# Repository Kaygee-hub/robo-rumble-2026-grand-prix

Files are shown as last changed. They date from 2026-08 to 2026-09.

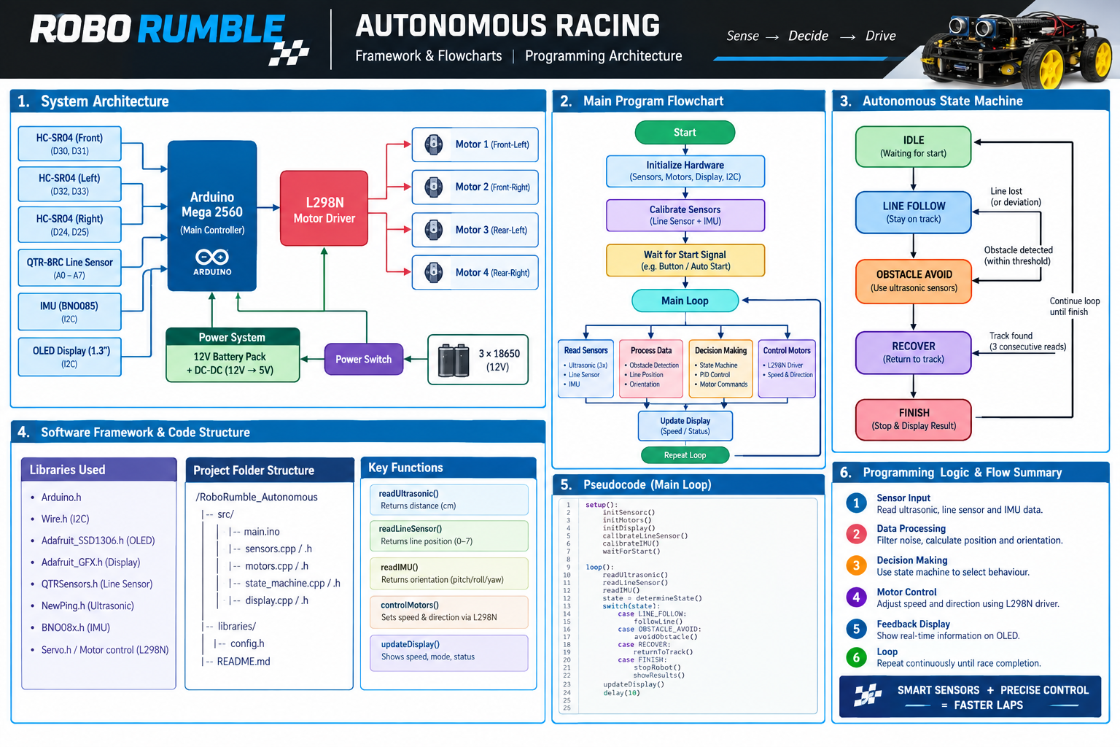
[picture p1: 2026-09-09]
robo-rumble-2026-grand-prix/Folder A - Source Code/flowcharts/robot rumble.png

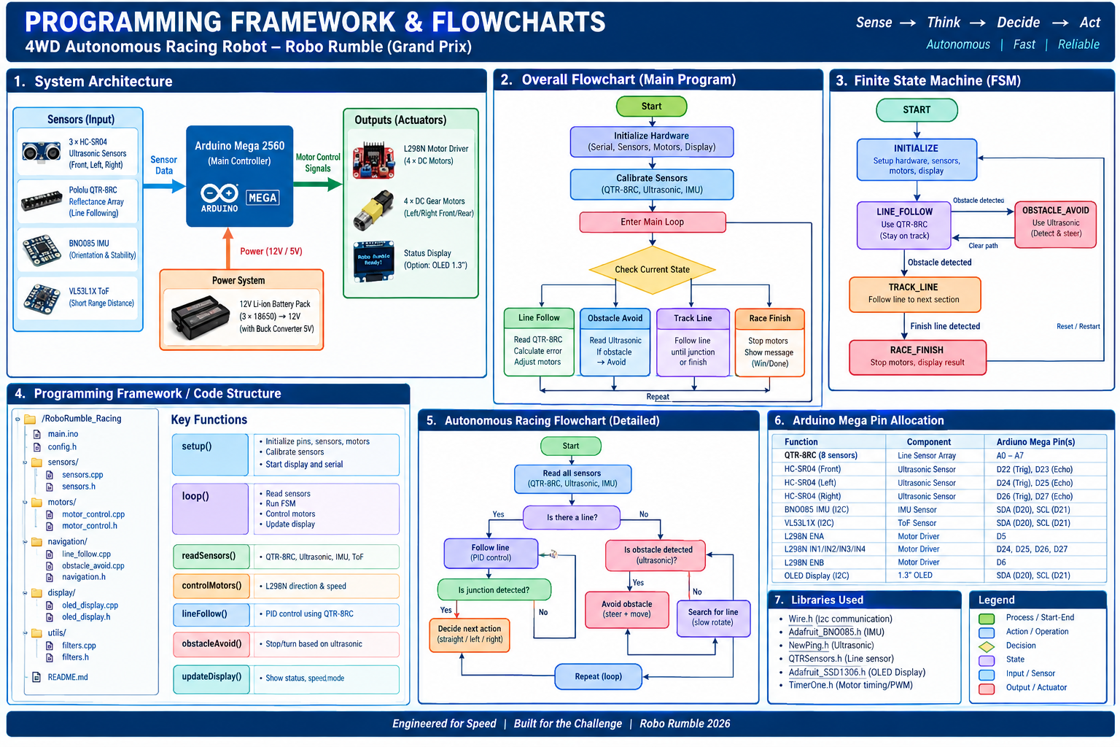
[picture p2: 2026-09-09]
robo-rumble-2026-grand-prix/Folder A - Source Code/flowcharts/flowchart and framework.png

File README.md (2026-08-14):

# 🏎️ Robo Rumble 2026: Autonomous 4WD Maze Racing Rover

> **Category:** Robo Grand Prix (Autonomous Racing)  
> **Platform:** 4WD Autonomous Mobile Robot  
> **Navigation:** Dynamic Wall-Sensing & Corridor Centering (No Line Tracking)  
> **Compliance:** Footprint $\le 50\text{ cm} \times 50\text{ cm}$ | Mass $< 5\text{ kg}$ | Integrated E-Stop Circuit  

---

## 📌 High-Level Project Summary

### What We Are Building
This project is an **autonomous 4WD mobile maze-racing rover** custom-engineered to compete in the **Robo Grand Prix** category at Robo Rumble 2026. Designed to navigate complex maze tracks without relying on surface line-following, the vehicle dynamically maps wall boundaries in real time, executes precision cornering, avoids dead ends, and maintains high velocity through narrow corridors—operating 100% autonomously with zero human intervention or remote control.

### How We Are Building It
* **Mechanical Frame:** A custom dual-deck lightweight chassis optimized for structural rigidity, staying well within the maximum $50\text{ cm} \times 50\text{ cm}$ footprint and $5\text{ kg}$ weight limit.
* **Drivetrain & Steering:** 4-wheel independent motor drive running on a differential skid-steering system managed by high-efficiency dual H-bridge motor drivers.
* **Perception & Ranging:** A multi-sensor array (Ultrasonic / Time-of-Flight distance sensors) mounted at the front, left, and right to measure corridor clearance and detect upcoming turns in real time.
* **Navigation & Control Architecture:** Embedded C++ firmware utilizing a closed-loop Proportional-Integral-Derivative (PID) wall-following algorithm combined with threshold logic for intersection decision-making.
* **Power & Safety Integrity:** Dual power management system separating microcontroller logic from high-current motor draws, featuring an accessible physical ON/OFF switch and a hardware-integrated **Emergency Stop (E-Stop)** circuit.

---

## 📂 Directory Map

```text
robo-rumble-2026-grand-prix/
│
├── 📁 Folder A - Source Code/           # Firmware, control algorithms, & logic diagrams
│   ├── 📄 src/                         # Arduino / C++ source code files
│   ├── 📄 flowcharts/                  # Navigation & maze decision logic flowcharts
│   └── 📄 README.md                    # Detailed software framework documentation
│
├── 📁 Folder B - Designs/               # Physical CAD, electrical schematics, & simulations
│   ├── 📄 Mechanical Design/           # 3D CAD renders, chassis assembly, & CAD files
│   ├── 📄 Electronic Design/           # Component selections & hardware justifications
│   ├── 📄 Schematics/                  # Annotated wiring schematics with E-Stop & Switch
│   └── 📄 Simulation/                  # Circuit & kinematic simulation test results
│
└── 📁 Folder C - Documentation/         # Submission files, budget, & attendance logs
    ├── 📄 Pitch Deck.pdf                # Official 7-slide project presentation
    ├── 📄 Bill_of_Materials.xlsx        # Itemized spreadsheet (Total Cost in RED)
    ├── 📄 Holistic_Build_Document.md    # Comprehensive technical engineering report
    ├── 📄 FQA_Attendance_Log.md         # Facilitator Q&A attendance logbook
    └── 📁 FQA_Proof/                    # Verified attendance proof screenshots

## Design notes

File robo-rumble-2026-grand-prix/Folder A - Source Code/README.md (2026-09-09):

### Software Architecture & Control Logic

1. **Sensor Processing Loop:** The firmware continuously samples three ultrasonic rangefinders (Front, Left, Right) using tight timing timeouts ($10\text{ ms}$) to ensure high execution loops without blocking execution.
2. **Obstacle Override Strategy:** If the front sensor registers an obstacle under $25\text{ cm}$, the PD controller suspends and the vehicle enters an in-place pivot turn toward whichever side offers greater clearance.
3. **Closed-Loop PD Corridor Centering:**
   * **Proportional ($K_p$):** Corrects lateral displacement relative to corridor walls.
   * **Derivative ($K_d$):** Dampens rapid oscillations and prevents high-speed weaving.
   * **Differential PWM:** Modulates left and right wheel speeds independently to maintain high velocity through sweeping corners without losing traction.

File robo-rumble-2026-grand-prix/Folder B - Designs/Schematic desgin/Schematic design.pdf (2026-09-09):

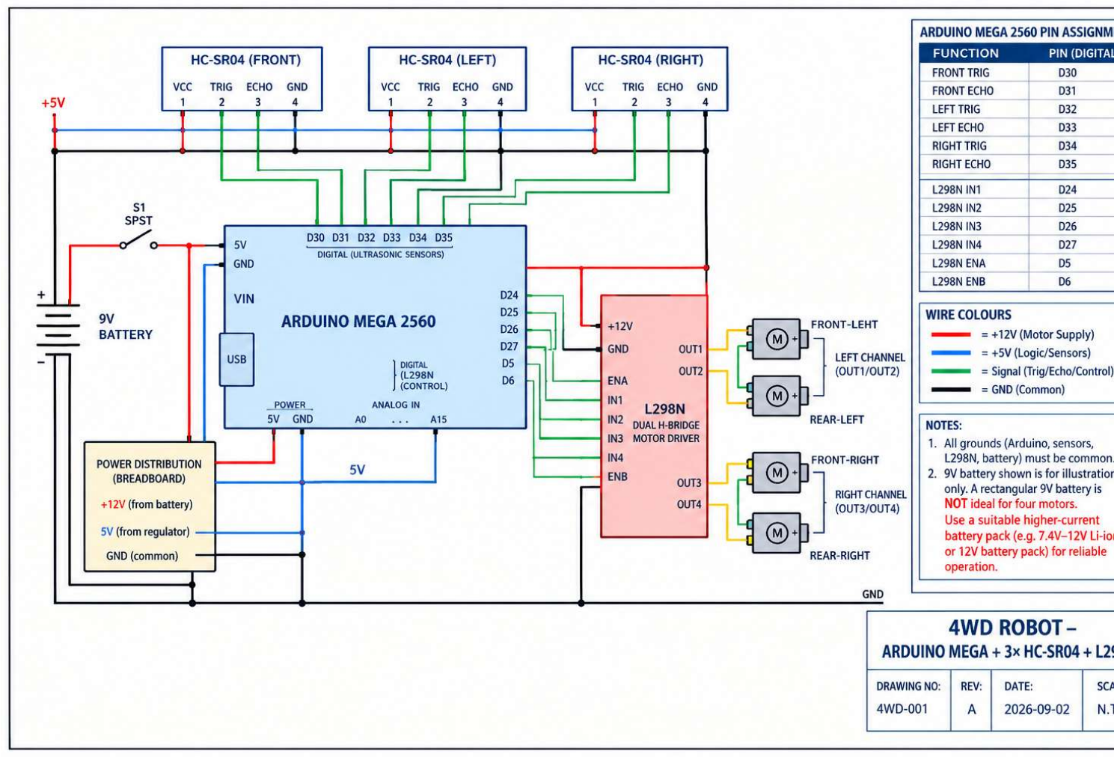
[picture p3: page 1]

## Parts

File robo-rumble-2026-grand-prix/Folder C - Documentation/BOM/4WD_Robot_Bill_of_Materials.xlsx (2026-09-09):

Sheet: BOM
4WD ROBOT — BILL OF MATERIALS
Arduino Mega 2560 + 3× HC-SR04 + L298N | Procurement BOM
Prepared: 2026-09-08 |  |  | Currency: ZAR (South African Rand) |  |  | Pricing basis: listed supplier price; VAT shown at 15% where applicable
PROJECT COST SUMMARY
Core BOM total (ex VAT) | 3854.29
VAT @ 15% | 578.14
FINAL TOTAL (INC VAT) | 4432.43
Item | Category | Component / Specification | Qty | Unit | Unit Cost (Ex VAT) | VAT / Unit | Line Total (Ex VAT) | VAT Total | Line Total (Inc VAT) | Supplier | Stock Code | Direct URL | Status / Notes
1 | Controller | Keyestudio SUPER Arduino Mega 2560 R3 Advanced + USB cable | 1 | each | 1186.77 | 178.02 | 1186.77 | 178.02 | 1364.79 | Mantech | 17M0214 | https://www.mantech.co.za/ProductInfo.aspx?Item=17M0214 | Matches Mega 2560 platform in schematic; listed ex VAT.
2 | Sensor | HC-SR04 ultrasonic reflective sensor | 3 | each | 71.19 | 10.68 | 213.57 | 32.04 | 245.61 | Mantech | 15M3173 | https://www.mantech.co.za/ProductInfo.aspx?Item=15M3173 | Three required: front, left, right.
3 | Motor Driver | Keyestudio L298N dual H-bridge motor driver module | 1 | each | 196.48 | 29.47 | 196.48 | 29.47 | 225.95 | Mantech | 17M0346 | https://www.mantech.co.za/ProductInfo.aspx?Item=17M0346 | One module drives two motor channels; motors are paired per channel.
4 | Drive Motor | 12V DC geared motor, 65RPM, 0.3A nominal, 6mm shaft | 4 | each | 496.85 | 74.53 | 1987.40 | 298.11 | 2285.51 | Mantech | 82M0808 | https://www.mantech.co.za/Stock.aspx?Query=motor%20dc%20geared | Mantech listing; verify live stock before purchase.
5 | Power | Energizer PP3 9V alkaline battery, 500–600mAh | 1 | each | 55.73 | 8.36 | 55.73 | 8.36 | 64.09 | Mantech | 310M0318 | https://www.mantech.co.za/ProductInfo.aspx?Item=310M0318 | Shown in the supplied schematic. Not recommended for sustained 4-motor operation; use a higher-current pack in the finished robot.
6 | Power Connection | 9V battery snap connector, 150mm leads | 1 | each | 3.44 | 0.52 | 3.44 | 0.52 | 3.96 | Mantech | 14M4029 | https://www.mantech.co.za/ProductInfo.aspx?Item=14M4029 | Battery clip for PP3 battery.
7 | Power | 12V→5V DC/DC buck converter, 3A, in-line USB | 1 | each | 91.30 | 13.69 | 91.30 | 13.69 | 104.99 | Communica | BDD DC/DC BUCK MOD 12TO5V USB IL | https://www.communica.co.za/products/bdd-dc-dc-buck-mod-12to5v-usb-il | Use for regulated 5V logic/sensors if supplied from a suitable motor battery.
8 | Switch | Illuminated red rocker switch, SPST, 12V, 15A | 1 | each | 10.89 | 1.63 | 10.89 | 1.63 | 12.52 | Mantech | 15M5438-X | https://www.mantech.co.za/ProductInfo.aspx?Item=15M5438-X | Main power switch; sized for low-voltage DC service.
9 | Prototyping | 830 tie-point solderless breadboard (MB-102 type) | 1 | each | 20.00 | 3.00 | 20.00 | 3.00 | 23.00 | Communica | CMU BREADBOARD 16,5X5,5CM 830TP | https://www.communica.co.za/collections/prototyping-products/products/cmu-breadboard-16-5x5-5cm-830tp | Power distribution/prototyping board.
10 | Wiring | 40-way male/female jumper ribbon, 15cm | 2 | pack | 20.00 | 3.00 | 40.00 | 6.00 | 46.00 | Communica | BMT RIBBON JUMPER 40W M/F 15CM | https://www.communica.co.za/products/bmt-ribbon-jumper-40w-m-f-15cm | Two packs provide ample logic wiring.
11 | Wiring | 40-way female/female jumper ribbon, 15cm | 1 | pack | 20.00 | 3.00 | 20.00 | 3.00 | 23.00 | Communica | HKD RIBBON JUMPER 40W F/F 15CM | https://www.communica.co.za/products/hkd-ribbon-jumper-40w-f-f-15cm | For module-to-module and breadboard connections.
12 | Mechanical / Electrical | Ultrasonic sensor mounting bracket, HC-SR04 compatible | 3 | each | 9.57 | 1.44 | 28.71 | 4.31 | 33.02 | Communica | HKD ULTRASONIC HC-SR04 BRACKET | https://www.communica.co.za/products/hkd-ultrasonic-hc-sr04-bracket | Optional but useful for clean mounting of the three sensors.
13 | Documentation / Note | Recommended high-current motor battery upgrade allowance | 0 | each | 0.00 | 0.00 | 0.00 | 0.00 | 0.00 | — | — | — | Excluded from total: the 9V PP3 shown in the reference circuit is not a suitable sustained source for four 12V motors.

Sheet: Source Notes
BOM SOURCE NOTES & ENGINEERING CHECKS
Topic | Finding | Implication | Action | Source | Date checked
9V battery vs motors | The schematic shows a 9V PP3 battery, while the listed motors are 12V geared motors. | A PP3 is unsuitable for sustained four-motor drive current. | Use a higher-current 7.4V–12V rechargeable battery pack for the actual robot; keep the 9V row only as the reference-circuit item. | https://www.mantech.co.za/ProductInfo.aspx?Item=310M0318 | 2026-09-08
HC-SR04 quantity | Three HC-SR04 modules are visible in the reference circuit. | One each for front, left and right coverage. | Procure exactly 3. | https://www.mantech.co.za/ProductInfo.aspx?Item=15M3173 | 2026-09-08
L298N | One L298N dual H-bridge is shown. | Two motor channels are available; the four motors are paired. | Procure 1 module. | https://www.mantech.co.za/ProductInfo.aspx?Item=17M0346 | 2026-09-08
Mega 2560 | The reference design uses Arduino Mega 2560. | The selected Keyestudio board is compatible with Mega 2560 R3. | Procure 1 board. | https://www.mantech.co.za/ProductInfo.aspx?Item=17M0214 | 2026-09-08
Pricing | Mantech prices displayed are ex VAT; Communica pages show ex and inc VAT. | Workbook standardizes to ex VAT + formula VAT at 15%. | Verify final cart pricing before purchase. | Supplier product pages linked in BOM. | 2026-09-08

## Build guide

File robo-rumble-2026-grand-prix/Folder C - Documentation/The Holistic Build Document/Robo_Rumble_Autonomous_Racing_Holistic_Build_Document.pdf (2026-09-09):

ROBO RUMBLE | AUTONOMOUS RACING | HOLISTIC BUILD DOCUMENT
Revision A | 08 September 2026 | Page 1

# ROBO RUMBLE

# AUTONOMOUS RACING

# Holistic Build Document

PROJECT BASELINE
Autonomous 4WD racing platform using Arduino Mega 2560, three HC-SR04 ultrasonic sensors, an L298N dual H-bridge, and four geared DC motors. The supplied 9V PP3 battery is retained only as the reference-circuit item; the finished racer should use a higher-current rechargeable motor battery.

Prepared for Robo Rumble / Robo Grand Prix — Autonomous Racing Competition date in project brief: 12 September 2026

# 1. Executive Summary

This build document defines the technical baseline for an autonomous racing robot intended for the Robo Rumble / Robo Grand Prix autonomous racing category. The objective is not simply to make a 4WD vehicle move, but to produce a compact, repeatable and serviceable platform that can sense its surroundings, make movement decisions without human steering, and convert those decisions into coordinated left/right motor commands.
The design uses an Arduino Mega 2560 as the central controller, three HC-SR04 ultrasonic sensors for front/left/right environment awareness, an L298N dual H-bridge for four-motor drive, and four geared DC motors arranged as two left motors and two right motors. The mechanical and electrical architecture is intentionally modular so that the control logic can be tuned without redesigning the full chassis.
- Primary race objective: maximize controllable speed while avoiding collisions and preserving a stable trajectory.
- Autonomy objective: all drive decisions are generated from on-board sensing and programmed logic; no steering input is required during the run.
- Engineering objective: remain inside the supplied category limits while keeping the center of mass low, wiring protected, and service access simple.
- Build objective: provide a clear verification trail from requirements -> wiring -> software -> testing -> competition readiness.
DESIGN STATUS
The document is written as Revision A using the circuit shown in the supplied reference image and the procurement BOM previously prepared. Physical prototype dimensions, exact chassis mass, motor current under load, and measured race speed must be verified on the assembled robot before a final competition release.

# 2. Background and Design Need

### 2.1 Problem Statement

In an autonomous race, the robot must react quickly enough to changes in path geometry or obstacles while maintaining traction and directional control. A manually driven 4WD platform can compensate for errors using a human operator, but an autonomous racer has to detect conditions, interpret them, and select a response inside a limited control cycle.
The technical challenge is therefore a closed-loop systems problem: sensing must be reliable, the controller must convert distance information into deterministic decisions, and the motor driver must apply those commands with enough electrical margin to avoid stalls, brownouts or uncontrolled resets.

### 2.2 Design Philosophy

- Keep the sensing geometry simple: one forward sensor establishes the primary collision-avoidance decision and two side sensors provide directional context.
- Treat left and right motor pairs as two drive channels. Differential speed between the channels provides steering without a conventional steering servo.
- Separate logic power from motor power through regulated supply and common ground architecture.
- Prefer deterministic state logic over unpredictable behavior. The robot should have explicit states such as READY, SEARCH, DRIVE, EVADE-LEFT, EVADE-RIGHT and SAFE-STOP.

- Design for debugging: named signals, documented pin assignments, accessible power switch and protected wiring.

# 3. Competition Category Constraints and Compliance

The following constraints are treated as the governing category requirements supplied for the Robo
Rumble / Robo Grand Prix autonomous racing entry. The compliance status should be rechecked against the organizer’s final technical inspection checklist immediately before scrutineering.
Constraint | Requirement | Design Response | Status | Verification
Footprint | Maximum 50 cm × 50 cm | Mechanical packaging must remain within the maximum footprint. | PASS BY DESIGN INTENT | Measure the complete outer envelope including sensors and wiring before inspection.
Mass | Maximum 5 kg | All chassis, electronics, battery and fasteners contribute to the competition mass. | TO VERIFY | Weigh the complete competition configuration.
Autonomy | Fully automatic | No manual steering/drive input during the race. | PASS BY ARCHITECTURE | Remove or disable any manual drive controls from the competition build.
Power | Battery only | Robot operates from onboard battery energy. | PASS BY ARCHITECTURE | Final battery must be onboard and isolated by the main switch.
Controller platform | Arduino / Raspberry Pi / STM accepted | The controller must belong to the accepted platform family. | PASS | Arduino Mega 2560 is used.
Category | Autonomous Racing / Grand Prix | Design emphasis is on autonomous navigation, speed, stability and repeatability. | PASS | Control strategy is closed-loop and sensor-driven.

INSPECTION GATE
A “PASS BY DESIGN INTENT” entry is not a measured certification. Final acceptance requires physical inspection of dimensions, mass, power system, wiring security and autonomous operation.

# 4. System Requirements

ID | Requirement | Meaning | Acceptance intent
FR-01 | Sense environment | Measure front, left and right distances using HC-SR04 sensors. | Three sensor channels shall be sampled repeatedly during autonomous operation.
FR-02 | Drive forward/reverse | Command coordinated motion of four motors through the L298N. | Left pair and right pair shall respond as two independently controlled drive channels.
FR-03 | Steer autonomously | Change heading using differential left/right wheel speed. | Controller shall be able to bias one side faster/slower and stop one side when required.
FR-04 | Avoid collision | Respond to insufficient | When distance falls below

| | clearance. | the configured safety threshold, drive command shall transition to an avoidance state.
FR-05 | Fail safe | Prevent uncontrolled movement on abnormal conditions. | Startup, sensor failure and battery/power faults shall lead to SAFE-STOP or controlled recovery.
FR-06 | Race repeatability | Run the same control sequence predictably. | Use deterministic thresholds, bounded delays and a documented state machine.
NFR-01 | Serviceability | Make faults easy to isolate. | Use labeled wiring, common ground rail, accessible connectors and modular electronics.
NFR-02 | Packaging | Fit the competition envelope. | Target a compact rectangular chassis below 50 × 50 cm with sensor mounts inside the outline.
NFR-03 | Electrical robustness | Avoid controller resets caused by motor transients. | Use separate regulated logic supply and sensible grounding/power distribution.

# 5. Exact Solution Architecture

### 5.1 Hardware Topology

The robot is a differential-drive 4WD platform. The Arduino Mega 2560 is the control core. Three HC-SR04 modules form a simple spatial sensing ring: FRONT, LEFT and RIGHT. The L298N provides two H-bridge channels; one channel is assigned to the left motor pair and the other to the right motor pair. Steering is achieved by creating a speed or direction difference between those two sides.

Subsystem | Component | Role
Controller | Arduino Mega 2560 | Runs sensor acquisition, decision logic and motor commands.
Front sensing | HC-SR04 #1 | Primary collision/clearance sensor.
Left sensing | HC-SR04 #2 | Left-side clearance / wall context.
Right sensing | HC-SR04 #3 | Right-side clearance / wall context.
Motor interface | L298N dual H-bridge | Converts controller IN/EN commands into power to the motor pairs.
Drive train | 4 × 12V geared DC motors | Two motors mechanically placed on the left side, two on the right.
Power | Onboard battery + regulated 5V rail | Motor rail feeds L298N; regulated 5V rail feeds controller/sensors as appropriate.
Main isolation | SPST power switch | Allows safe energization/de-energization of the robot.

### 5.2 Electrical Pin Assignment

Signal | Mega pin | Function
FRONT TRIG | D30 | HC-SR04 front
FRONT ECHO | D31 | HC-SR04 front
LEFT TRIG | D32 | HC-SR04 left
LEFT ECHO | D33 | HC-SR04 left
RIGHT TRIG | D34 | HC-SR04 right

RIGHT ECHO | D35 | HC-SR04 right
L298N IN1 | D24 | Drive control
L298N IN2 | D25 | Drive control
L298N IN3 | D26 | Drive control
L298N IN4 | D27 | Drive control
L298N ENA | D5 | Left-channel enable / PWM
L298N ENB | D6 | Right-channel enable / PWM

### 5.3 Wiring Rules

- All grounds are common: Arduino, HC-SR04 modules, L298N logic/control ground and battery negative must share a defined ground path.
- Motor current must not be routed through the breadboard logic traces where a dedicated motor-power path is available.
- Use a regulated 5V supply for the Mega/sensors where the battery voltage is higher than 5V.
- Keep sensor signal wires away from high-current motor wires where practical, and secure loose leads so vibration cannot change the sensor orientation.
- Use the main switch to isolate the robot before connecting or disconnecting wiring.

### 5.4 Reference Electrical Schematic

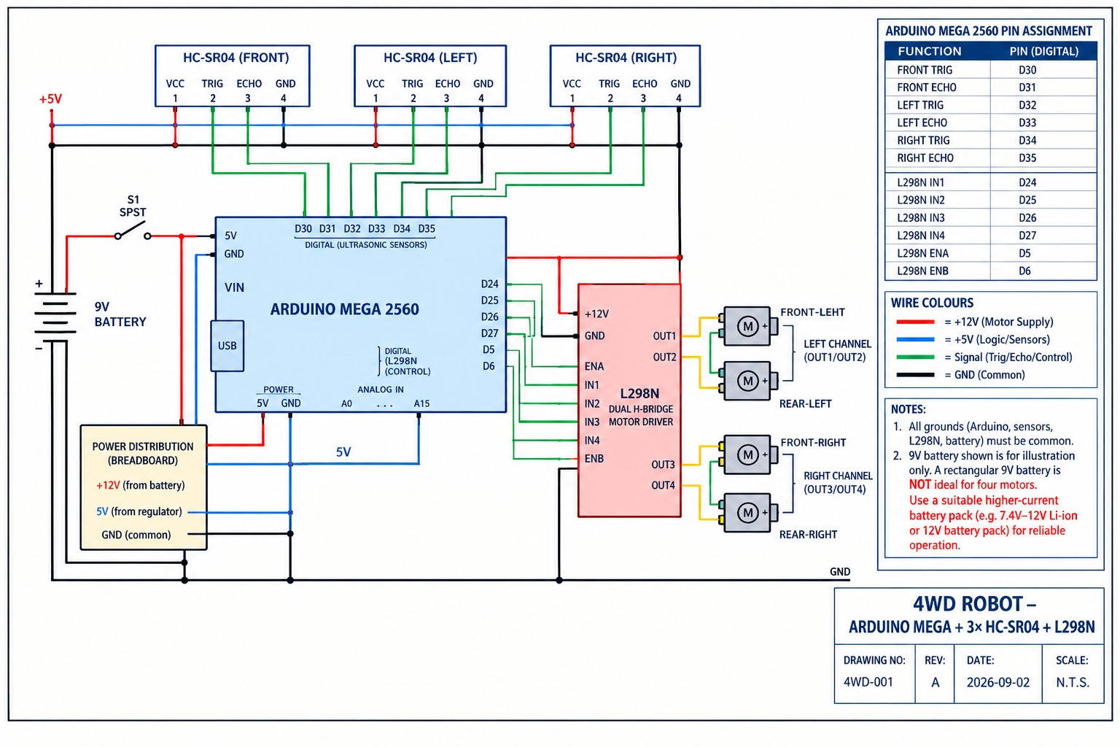
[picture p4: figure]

Figure 1 — Reference schematic. Treat the 9V PP3 as illustrative only; the finished four-motor platform needs a higher-current rechargeable pack.

# 6. Mechanical Design

### 6.1 Chassis Architecture

The mechanical design should use a rigid rectangular base with four driven wheels located symmetrically around the centerline. Heavy components such as the battery and motor driver should sit low and near the geometric center. The Arduino and sensor wiring can sit on an upper electronics deck provided the resulting center of gravity remains low enough to limit wheel lift during hard turns.
- Four-wheel drive provides traction and redundancy; left and right motor pairs act as logical drive channels.
- Sensor brackets should keep the three HC-SR04 faces square to their intended directions. Small angular errors can create uneven distance readings and false steering decisions.
- Protect electronics from wheel spray, loose wires and impact contact. A simple raised electronics plate is preferred to mounting modules directly against the floor.
- Fasteners should be mechanically locked against vibration where required. Cable ties or printed cable guides should restrain heavy motor leads.

### 6.2 Packaging and Envelope Control

Parameter | Design guidance
Maximum allowed footprint | 500 × 500 mm
Target design margin | Keep the measured outer envelope comfortably below the limit instead of designing to the boundary.
Sensor extension | Sensor brackets and connector plugs count toward the practical envelope and should be included in inspection measurement.
Battery placement | Low and central to reduce pitch/roll moment during acceleration and avoidance.
Maintenance | Allow access to the main switch, battery connector, controller USB port and motor-driver terminals.

### 6.3 Drive Geometry and Steering

For differential steering, the robot yaw response depends on the speed difference between the left and right sides. A simple normalized control law is:
CONTROL LAW
left_cmd = base_speed + steer_bias; right_cmd = base_speed - steer_bias. Positive steer_bias produces a left/right speed difference; sign convention must be fixed during software commissioning.

The exact steering gain and base speed should be tuned experimentally because motor torque, wheel diameter, surface friction, battery voltage and chassis loading determine the actual turning response.

# 7. Sensing and Perception

### 7.1 HC-SR04 Operating Concept

Each HC-SR04 is activated by a trigger pulse and reports the time between the transmitted ultrasonic burst and the returning echo. Distance is calculated from the measured round-trip time and the speed of sound. A commonly used relationship is d = v_sound × t / 2. At approximately 20 °C, v_sound is about 343 m/s.

For an autonomous racer, raw readings should not be used blindly. The controller should reject obviously invalid readings, apply a small median or moving-average filter where needed, and use thresholds with hysteresis so the robot does not chatter between two movement states.

### 7.2 Sensor Placement

Sensor | Purpose | Mounting | Control use
Front | Primary collision clearance | Forward-facing on centerline | Controls emergency braking / avoidance decision
Left | Left clearance / corridor context | Forward-left or left-facing | Biases steering away from close left boundary
Right | Right clearance / corridor context | Forward-right or right-facing | Biases steering away from close right boundary

### 7.3 Recommended Measurement Logic

1. Trigger one sensor and measure echo time.
2. Convert the valid time measurement to distance.
3. Reject readings outside the sensor’s usable range or with a timeout.
4. Repeat for the other sensors using a schedule that prevents overlapping acoustic bursts.
5. Feed the filtered values into the decision state machine.
6. If the front distance falls below the emergency threshold, reduce base speed immediately and select the avoidance direction using side clearances.
IMPORTANT
The three ultrasonic sensors should not be fired simultaneously. Staggering measurements reduces the chance that one sensor hears another sensor’s echo.

# 8. Motor Drive and Power System

### 8.1 Motor Driver Topology

The L298N is a dual H-bridge. In this four-motor implementation, the two left motors are paired on one bridge channel and the two right motors are paired on the second bridge channel. IN1/IN2 determine the left channel direction; IN3/IN4 determine the right channel direction; ENA and ENB enable the channels and can accept PWM for speed control.

### 8.2 Recommended Command Table

Action | Left channel | Right channel | Intent
FORWARD | IN1=1, IN2=0 | IN3=1, IN4=0 | Both sides forward
REVERSE | IN1=0, IN2=1 | IN3=0, IN4=1 | Both sides reverse
LEFT | Reduced left / stopped left | Right forward | Pivot or arc left, depending on tuning
RIGHT | Left forward | Reduced right / stopped right | Pivot or arc right, depending on tuning
BRAKE/STOP | 0/0 or implementation-specific | 0/0 or implementation-specific | Stop command; verify module behavior on the actual board

### 8.3 Battery and Power Budget

The procurement BOM contains a 9V PP3 battery because it is shown in the reference circuit. That battery is not an appropriate sustained source for four 12V geared motors. The competition build therefore requires a higher-current rechargeable battery pack that can supply the motor load and transient current without excessive voltage sag.
- Motor rail: choose a battery voltage compatible with the selected geared motors and the L298N operating range.
- Logic rail: derive a regulated 5V supply for the Arduino/sensors when the battery voltage is above 5V.
- Common ground: connect battery negative, driver ground and logic ground at a deliberate distribution point.
- Protection: include a master switch and, where practical, a fuse or current-limiting protection appropriate to the pack and wiring.
POWER WARNING
Do not treat the 9V PP3 as the final race battery for a four-motor drive train. The final hardware configuration must be verified for motor voltage, driver dissipation, current capability and battery discharge rating.

# 9. Autonomous Control Software

### 9.1 Software Architecture

Module | Responsibility
Initialization | Configure I/O, PWM channels, sensor timeouts and safety defaults.
Sensor service | Acquire front/left/right measurements on a staggered schedule.
Filtering | Validate and smooth readings; mark invalid data explicitly.
Decision engine | Convert distance context into a state such as DRIVE or EVADE.
Motion controller | Map the state into left/right motor direction and PWM commands.
Safety monitor | Stop or slow the robot when sensing fails, battery/logic resets occur or an invalid state is detected.
Telemetry/debug | During development only, expose readings and states through Serial; remove or minimize blocking debug output for final racing timing.

### 9.2 Suggested State Machine

State | Action | Entry condition
READY | Waiting for start condition; motors disabled. | Main switch on; controller healthy.
DRIVE | Normal forward racing. | No immediate obstacle and sensors valid.
SLOW | Reduce speed before close geometry. | Front distance entering warning band.
EVADE-LEFT | Bias or pivot left. | Left side offers more clearance than right, or route logic selects left.
EVADE-RIGHT | Bias or pivot right. | Right side offers more clearance than left, or route logic selects right.
RECOVER | Controlled re-acquisition of heading. | Robot has completed avoidance and needs to return to preferred trajectory.
SAFE-STOP | Motors disabled. | Sensor timeout, controller fault, emergency stop condition or shutdown.

### 9.3 Pseudocode

START
initialize pins, PWM, sensors, safety defaults motorStop()
state <- READY

LOOP
front <- readFront()
left <- readLeft()
right <- readRight()

if invalid(front, left, right):
state <- SAFE-STOP
else if front < EMERGENCY_DISTANCE:
if left > right: state <- EVADE-LEFT else: state <- EVADE-RIGHT
else if front < WARNING_DISTANCE: state <- SLOW
else:
state <- DRIVE

applyMotorCommand(state, left, right, front) waitUntilNextControlCycle()

# 10. Race Control and Tuning Strategy

### 10.1 Speed Strategy

A fast robot is not the same as a successful racer. The control strategy should trade speed for predictability near obstacles or tight sections of the course. A practical implementation uses at least two speed bands: a higher base speed in clear space and a reduced speed when the front sensor enters the warning zone.

### 10.2 Thresholds

Parameter | Purpose | Engineering basis
WARNING_DISTANCE | Start reducing speed | Tune from measured stopping distance + margin.
EMERGENCY_DISTANCE | Initiate decisive avoidance or stop | Must exceed the robot’s worst-case stopping distance at the selected race speed.
SIDE_BIAS_THRESHOLD | Select left vs right path | Derived from difference between left and right measured clearance.
SENSOR_TIMEOUT | Declare sensing fault | Short enough to fail safe, long enough not to false-trigger on noisy returns.

### 10.3 Basic Stopping-Distance Method

For commissioning, measure actual stopping distance instead of assuming a theoretical value. Conduct repeat runs at the intended race speed, record the distance from obstacle detection to complete stop, and define the emergency threshold as the measured worst case plus a safety margin. This converts the avoidance logic from an arbitrary number into a verified engineering parameter.

# 11. Verification and Testing Plan

ID | Test | Method | Pass criterion
V-01 | Power-up test | Switch on; Arduino starts; no | No unintended motion; logic

| | motor movement at startup. | supply stable.
V-02 | Sensor range test | Place target at known distances front/left/right. | Reported distance tracks target with acceptable repeatability.
V-03 | Sensor cross-talk test | Trigger sensors in sequence with all three mounted. | No persistent false echoes caused by another sensor.
V-04 | Motor direction test | Command each drive channel separately. | Left pair and right pair rotate in the documented directions.
V-05 | Differential steering test | Run forward with fixed left/right PWM offsets. | Robot turns in the expected direction consistently.
V-06 | Obstacle avoidance test | Drive toward obstacle at controlled speed. | Robot slows/turns before collision; repeated runs are consistent.
V-07 | Full autonomous lap test | Run complete course with no manual intervention. | Completes the course within the intended safety and repeatability envelope.
V-08 | Power endurance test | Operate at representative race load. | No controller resets, dangerous heating or loose connections.
V-09 | Inspection test | Measure envelope and mass. | Footprint <= 50x50 cm and mass <= 5 kg.

# 12. Risk, Failure Modes and Mitigations

Failure mode | Effect | Risk | Mitigation
Motor current overload | L298N heating / voltage drop | High | Use suitable battery/driver thermal margin; test loaded drive; avoid stalled motors.
9V PP3 used in final build | Rapid voltage sag / motors unable to deliver torque | High | Replace reference battery with a suitable high-current rechargeable pack.
Sensor cross-talk | False distance reading | Medium | Stagger sensor triggering; filter invalid readings.
Loose motor wire | Intermittent drive / resets | Medium | Strain relief, locking connectors and post-vibration inspection.
Common-ground error | Erratic sensors / driver behavior | High | Use a defined common ground distribution point and continuity test.
Sensor misalignment | Robot steers unpredictably | Medium | Rigid brackets and alignment check during pre-run inspection.
Controller reset | Loss of autonomy | High | Separate logic power from motor rail; minimize electrical noise and brownout risk.
Excess speed for course | Overshoot / collision | Medium | Use speed bands and verify stopping distance empirically.

# 13. Bill of Materials and Cost Position

The separate procurement workbook prepared for this project totals the currently listed reference build at R4,432.43 including VAT. That total includes the 9V PP3 line shown in the reference circuit; the recommended higher-current final motor battery is excluded from the current total and must be budgeted separately.

Group | Qty | Component | Cost / note
Controller | 1 | Arduino Mega 2560 | R1,364.79 incl. VAT (from

| | | current BOM)
Ultrasonic sensing | 3 | HC-SR04 | R81.87 incl. VAT each (from current BOM)
Motor driver | 1 | L298N | R226.95 incl. VAT (from current BOM)
Drive motors | 4 | 12V geared 65RPM motors | R571.38 incl. VAT each (from current BOM)
Reference power | 1 | 9V PP3 | Not suitable as the final motor battery
Other electrical/mechanical | Various | Switch, buck, breadboard, jumpers, brackets, clip | Included in BOM total

CURRENT BOM TOTAL
R4,432.43 incl. VAT — visually treated as a reference procurement total only. Final race cost should be updated after selecting the compliant high-current battery and any final chassis/manufacturing hardware.

# 14. Build, Assembly and Service Procedure

7. Assemble the chassis and verify wheel alignment without powering electronics.
8. Mount the four motors and confirm that all wheels spin freely and have the intended direction convention.
9. Install the L298N close to the motor wiring but protected from impact and conductive debris.
10. Mount the Arduino Mega and establish the regulated logic power rail.
11. Install and align the three HC-SR04 sensors with rigid brackets.
12. Create the common ground distribution and then route sensor/control signals separately from motor-current wiring.
13. Load the autonomous control firmware and execute startup, direction and sensor tests individually.
14. Only after bench verification, energize the complete system with the final competition battery.

### 14.1 Pre-Race Checklist

☐ Footprint measured below 50 × 50 cm.
☐ Complete robot mass measured below 5 kg.
☐ Battery securely mounted and isolated by main switch. ☐ No loose wires near wheels, gears or moving linkages. ☐ All three sensor brackets tight and correctly oriented. ☐ Motor direction verified.
☐ Sensor values verified before every run.
☐ Autonomy tested without manual steering.
☐ Emergency/stop procedure understood by the team.

# 15. Technical Rationale and Expected Performance

The main advantage of the selected architecture is simplicity. The Arduino Mega provides many digital I/O resources, the three ultrasonic modules are straightforward to integrate, and the L298N reduces the motor interface to two drive channels. This lowers software complexity and makes the first autonomous prototype easy to debug.

The main limitation is power and drive efficiency. The L298N introduces voltage loss and heat compared with newer MOSFET-based motor drivers, and the reference 9V PP3 cannot support sustained four-motor racing. Therefore, the performance envelope must be characterized experimentally rather than assumed. The highest-value improvements are a suitable high-current battery, robust power distribution, wheel alignment, sensor timing, and tuned differential steering.

### 15.1 Engineering Metrics to Record

ID | Metric | Unit | Measurement method
M-01 | Top sustainable speed | m/s | 10-run average on the actual race surface
M-02 | Stopping distance | cm | Worst case at race speed
M-03 | Sensor repeatability | cm | Standard deviation over repeated stationary tests
M-04 | Motor-driver temperature rise | °C | After representative continuous drive
M-05 | Runtime / course attempts | min or laps | Measure under representative battery condition
M-06 | Mass | kg | Competition configuration
M-07 | Footprint | mm × mm | Maximum external dimensions

# 16. Why This Fits Autonomous Racing

This platform is deliberately optimized around the key demands of autonomous racing: short decision cycles, simple but useful environmental perception, differential traction control, compact packaging and repeatable behavior. The robot does not depend on a human steering command during the run. Instead, the on-board controller closes the loop between measured distance and motor command.
RACING PRINCIPLE
Consistency beats theoretical peak speed. The preferred setup is the fastest configuration that can repeatedly complete the course without sensor-induced oscillation, motor-driver thermal problems or loss of traction.

# 17. Conclusion

The documented solution is a practical autonomous 4WD racer built around an Arduino Mega 2560, three ultrasonic sensors and a dual-channel motor driver. It meets the stated autonomous architecture requirements and provides a clear path from electrical integration to race tuning. The remaining engineering work is primarily validation: measure the complete robot, select and qualify the final high-current battery, tune the autonomous thresholds, and verify repeated full-course performance. Revision A should be treated as the build-control baseline. Any change to controller, sensor count, motor driver, battery voltage, wheel diameter or pin assignment should trigger a controlled revision so that the wiring diagram, firmware and procurement list remain consistent.

# Appendix A — Procurement Reference

The current BOM workbook should be treated as the procurement source of truth for component names, quantities, supplier references, stock codes and direct product URLs. Before purchase, verify live pricing, stock and the final battery specification.
Workbook: /mnt/data/4WD_Robot_Bill_of_Materials.xlsx

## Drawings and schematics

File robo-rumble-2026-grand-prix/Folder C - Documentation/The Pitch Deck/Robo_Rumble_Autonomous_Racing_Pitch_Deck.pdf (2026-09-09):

# ROBO

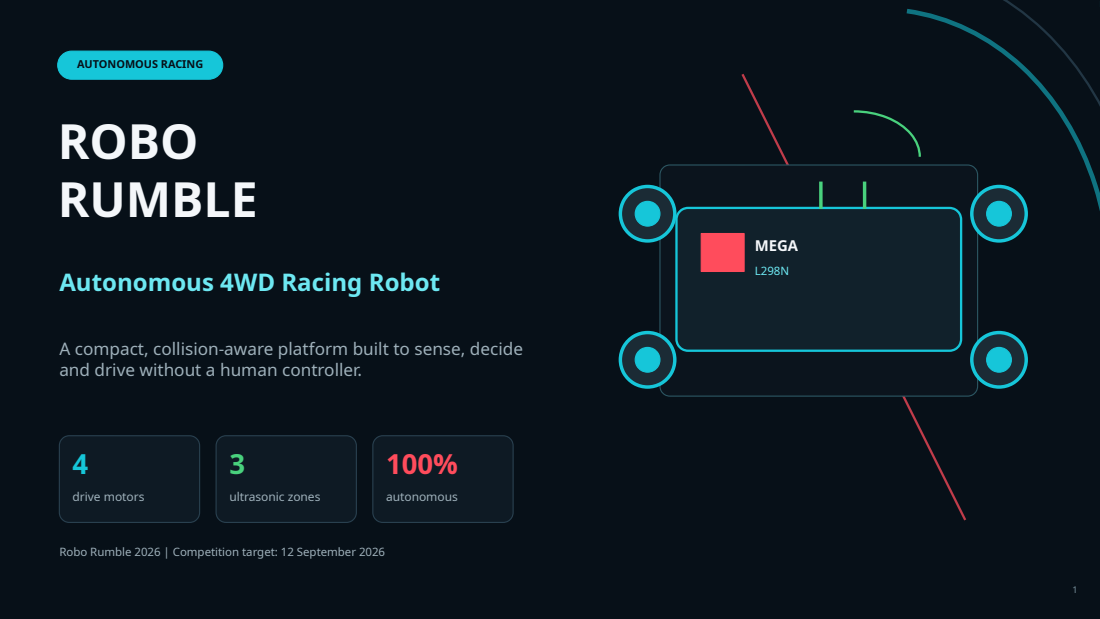
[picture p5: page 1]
ROBO RUMBLE 2026 | AUTONOMOUS RACING; KGAOGELO / KICT; AUTONOMOUS RACING; RUMBLE; drive motors; ultrasonic zones; autonomous; MEGA

Autonomous 4WD Racing Robot

A compact, collision-aware platform built to sense, decide
and drive without a human controller.

Robo Rumble 2026 | Competition target: 12 September 2026

01 | THE PROBLEM

# Autonomous racing needs more than speed

The challenge is maintaining momentum while reacting to changing track conditions in real time.

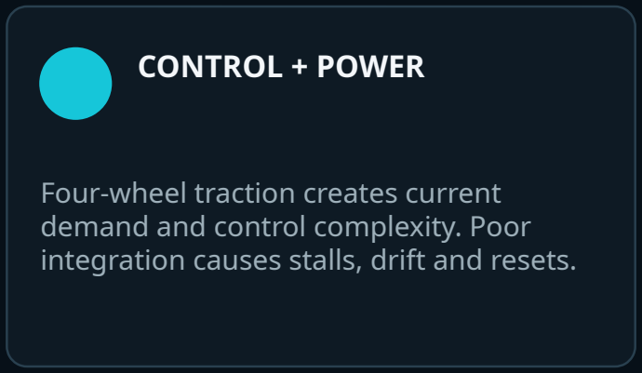
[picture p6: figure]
CONTROL + POWER; Four-wheel traction creates current demand and control complexity. Poor

integration causes stalls, drift and resets.

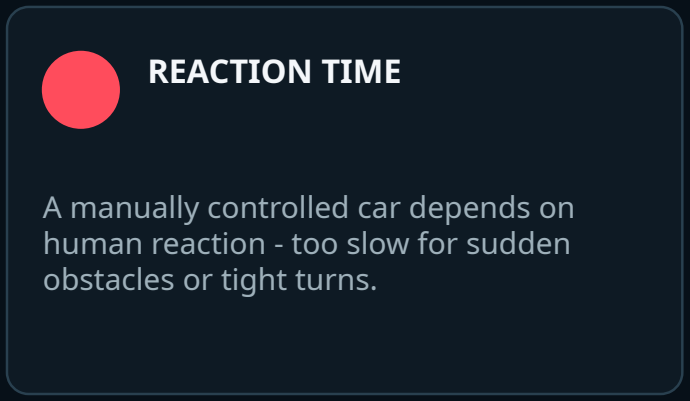
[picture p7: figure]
REACTION TIME; A manually controlled car depends on human reaction - too slow for sudden obstacles or tight turns.
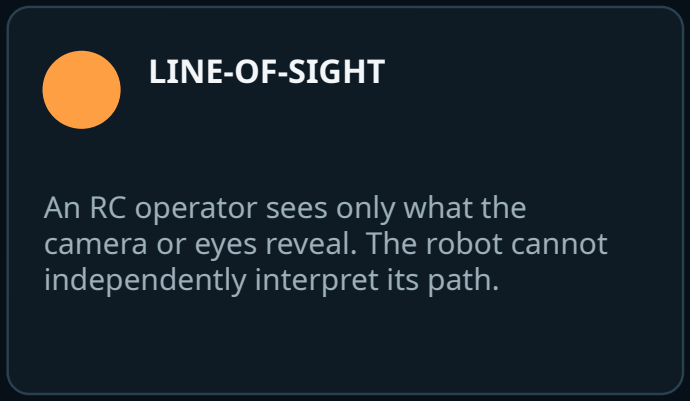
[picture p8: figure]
LINE-OF-SIGHT; An RC operator sees only what the camera or eyes reveal. The robot cannot independently interpret its path.
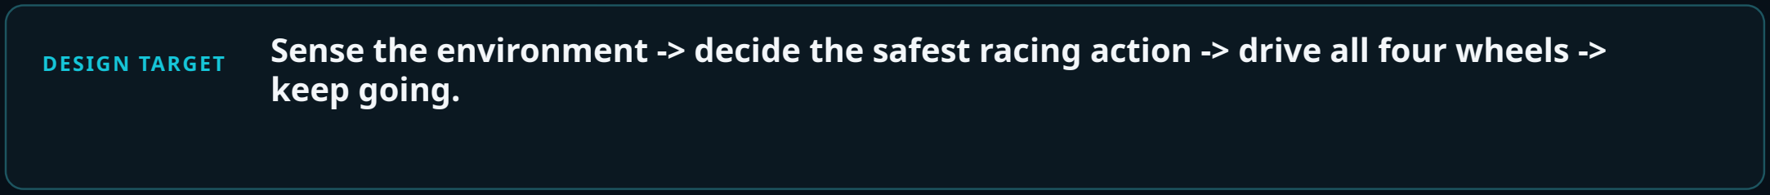
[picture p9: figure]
keep going.

DESIGN TARGET Sense the environment -> decide the safest racing action -> drive all four wheels ->

Competition brief used: compact footprint, battery-powered, fully autonomous operation.

# A three-zone sensing system wrapped around a 4WD drive platform

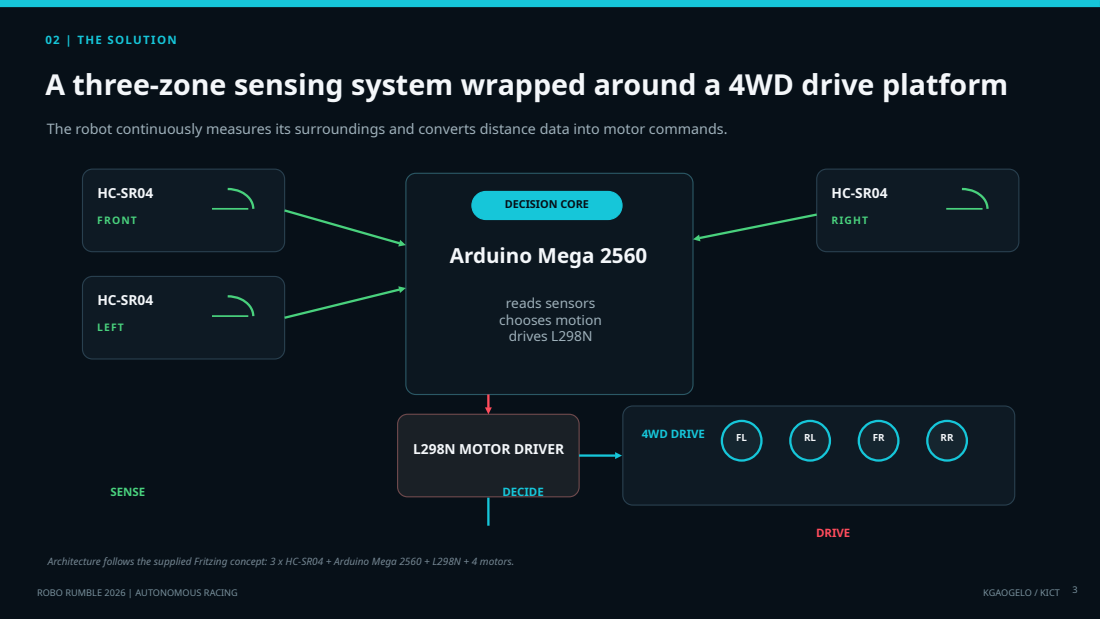
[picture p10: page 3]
02 | THE SOLUTION; DECISION CORE; Arduino Mega 2560; reads sensors chooses motion drives L298N; FRONT; LEFT; RIGHT; L298N MOTOR DRIVER; 4WD DRIVE; SENSE; DECIDE; DRIVE

The robot continuously measures its surroundings and converts distance data into motor commands.

Architecture follows the supplied Fritzing concept: 3 x HC-SR04 + Arduino Mega 2560 + L298N + 4 motors.

Simple rules. Fast decisions. Fewer collisions.

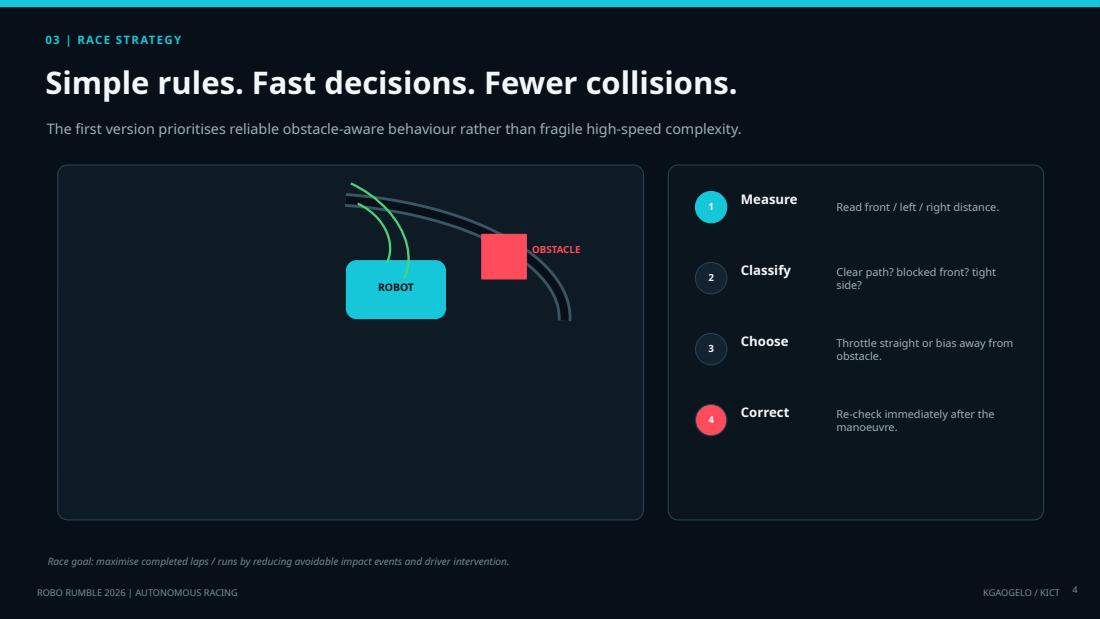
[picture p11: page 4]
03 | RACE STRATEGY; ROBOT; OBSTACLE; Measure; Read front / left / right distance.; Classify; Clear path? blocked front? tight; side?; Choose; Throttle straight or bias away from; obstacle.; Correct; Re-check immediately after the; manoeuvre.

The first version prioritises reliable obstacle-aware behaviour rather than fragile high-speed complexity.

Race goal: maximise completed laps / runs by reducing avoidable impact events and driver intervention.

04 | MARKETABILITY

# A competition robot can become a reusable robotics platform

The same sensing-and-drive architecture transfers to education, demos and lightweight indoor automation.

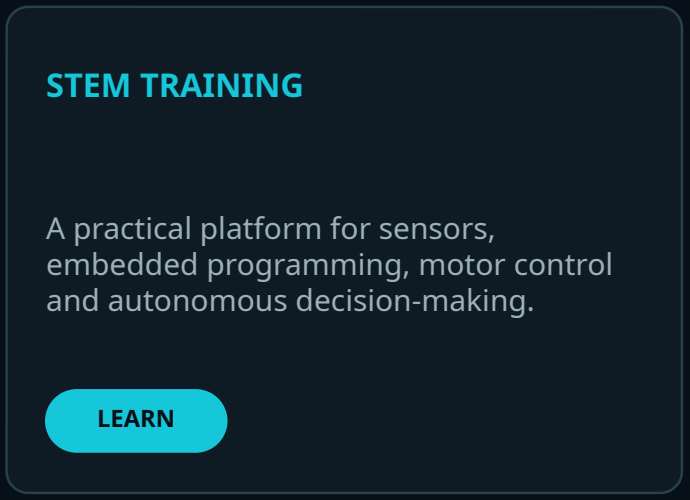
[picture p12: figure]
STEM TRAINING; A practical platform for sensors, embedded programming, motor control and autonomous decision-making.; LEARN
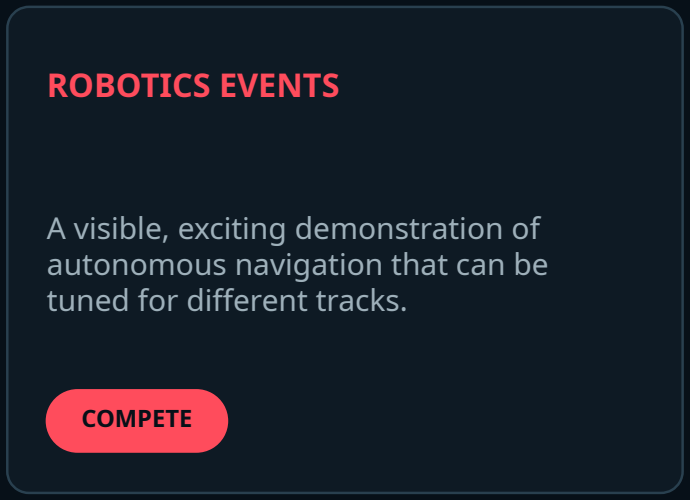
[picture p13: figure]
ROBOTICS EVENTS; A visible, exciting demonstration of autonomous navigation that can be tuned for different tracks.; COMPETE
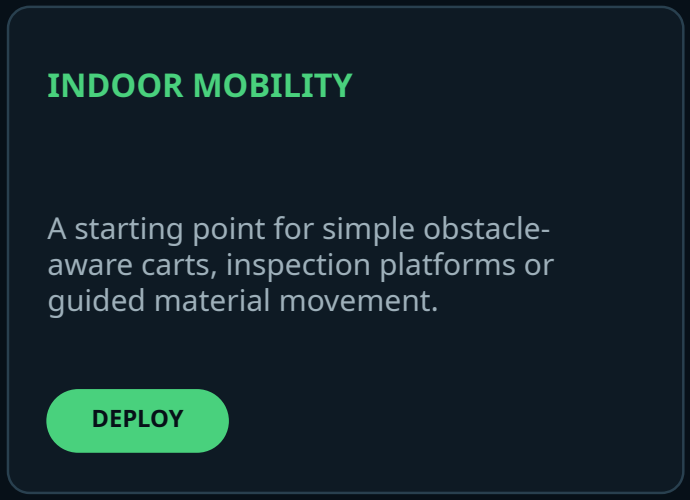
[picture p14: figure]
INDOOR MOBILITY; A starting point for simple obstacle- aware carts, inspection platforms or guided material movement.; DEPLOY
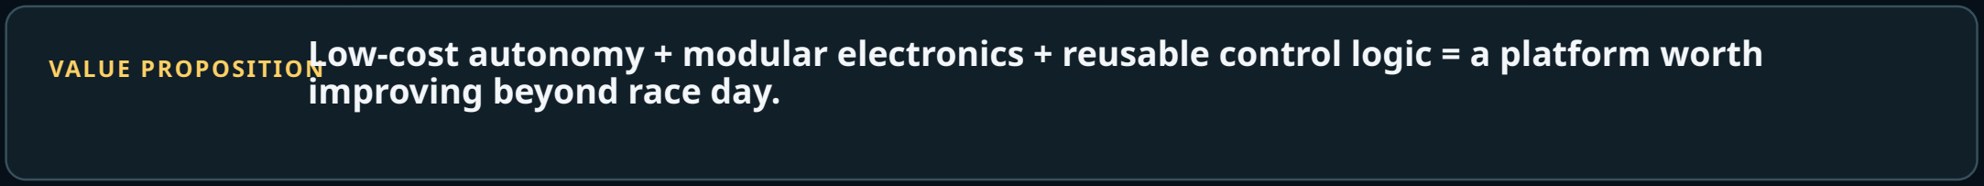
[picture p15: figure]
improving beyond race day.

VALUE PROPOSITIONLow-cost autonomy + modular electronics + reusable control logic = a platform worth

Commercial framing is a project proposition, not a claim of current commercial deployment.

05 | COST

# Built with accessible off-the-shelf electronics

The current BOM stays within a student-project budget while keeping the platform serviceable and upgradeable.

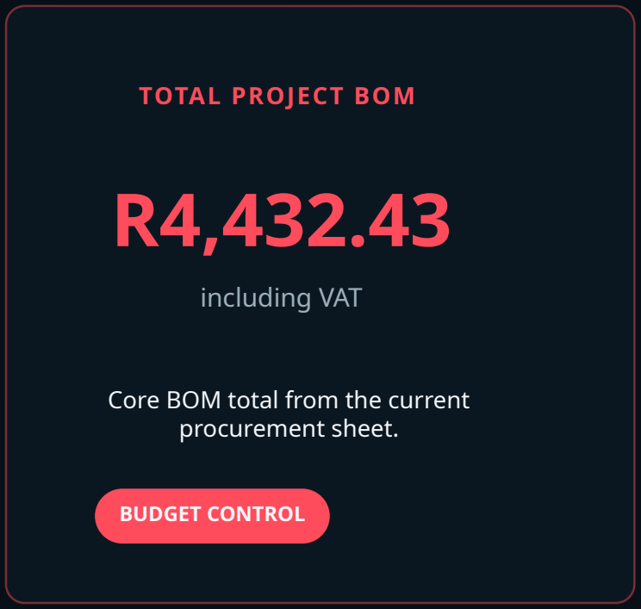
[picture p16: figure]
TOTAL PROJECT BOM R4,432.43; including VAT; Core BOM total from the current procurement sheet.; BUDGET CONTROL

COST DRIVERS

4 x drive motors | ~R2,285
Mega + sensors + L298N | ~R1,485
Power + wiring + mechanics | ~R662

POWER NOTE: the 9V PP3 shown in the reference circuit is not suitable for sustained four-motor operation; use a higher-current rechargeable pack in the finished race robot.

Pricing basis: current BOM sheet, ZAR; verify supplier stock and final cart pricing before purchase.

# The person behind the machine

06 | TEAM; Kgaogelo “KayGee”; TEAM LEAD; EMBEDDED SYSTEMS; MECH / ELECTRICAL; TEST / TUNING

Hands-on integration across mechanics, electronics, firmware and race testing.

Project direction + race strategy

Arduino control + sensor logic

Drive train + wiring integration

Track trials + decision-rule tuning

MISSION Build an autonomous robot that is fast enough to compete,

simple enough to repair, and smart enough to finish.

Team slide uses the uploaded member photo supplied in this conversation.

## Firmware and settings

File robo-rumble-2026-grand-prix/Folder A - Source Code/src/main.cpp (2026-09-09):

/**
 * Robo Rumble 2026 — Robo Grand Prix (Autonomous Maze Racing)
 * 4WD Rover High-Speed Wall-Centering & Navigation Firmware
 * 
 * Hardware:
 * - Microcontroller: Arduino Uno / Nano / Mega
 * - Driver: L298N / DRV8833 Dual H-Bridge
 * - Sensors: 3x HC-SR04 Ultrasonic Sensors (Front, Left, Right)
 */

#include <Arduino.h>

// ==========================================
// 1. PIN CONFIGURATIONS
// ==========================================

// Motor Driver Pins (L298N / DRV8833)
const int ENA = 5;   // PWM Speed Control Left Motors
const int IN1 = 4;   // Direction Left Forward
const int IN2 = 7;   // Direction Left Reverse

const int ENB = 6;   // PWM Speed Control Right Motors
const int IN3 = 8;   // Direction Right Forward
const int IN4 = 12;  // Direction Right Reverse

// Ultrasonic Sensor Pins
const int TRIG_FRONT = 2;
const int ECHO_FRONT = 3;

const int TRIG_LEFT  = 9;
const int ECHO_LEFT  = 10;

const int TRIG_RIGHT = 11;
const int ECHO_RIGHT = 13;

// ==========================================
// 2. RACING TUNING PARAMETERS
// ==========================================
const int MAX_SPEED       = 255;  // Full speed PWM (0 - 255)
const int BASE_SPEED      = 220;  // Cruising speed on straightaways
const int MIN_SPEED       = 100;  // Minimum wheel PWM during tight turns

const int FRONT_THRESHOLD = 25;   // Critical distance (cm) to trigger cornering
const int SENSOR_TIMEOUT  = 10000; // Timeout in microseconds (~170cm max distance limit)

// PD (Proportional-Derivative) Control Gains
float Kp = 6.5;                   // Steering aggression (Increase if weaving too late)
float Kd = 3.2;                   // Steering damping (Increase if rover oscillates/wobbles)

// Steering variables
float currentError = 0.0;
float lastError    = 0.0;

// Sensor Distance Variables (cm)
float distFront, distLeft, distRight;

// ==========================================
// 3. FUNCTION DECLARATIONS
// ==========================================
float getDistance(int trigPin, int echoPin);
void readAllSensors();
void setMotorSpeeds(int leftSpeed, int rightSpeed);
void executePivotTurn();

// ==========================================
// 4. SETUP
// ==========================================
void setup() {
  // Motor Pins
  pinMode(ENA, OUTPUT);
  pinMode(ENB, OUTPUT);
  pinMode(IN1, OUTPUT);
  pinMode(IN2, OUTPUT);
  pinMode(IN3, OUTPUT);
  pinMode(IN4, OUTPUT);

  // Ultrasonic Pins
  pinMode(TRIG_FRONT, OUTPUT);
  pinMode(ECHO_FRONT, INPUT);
  pinMode(TRIG_LEFT, OUTPUT);
  pinMode(ECHO_LEFT, INPUT);
  pinMode(TRIG_RIGHT, OUTPUT);
  pinMode(ECHO_RIGHT, INPUT);

  // Initial Motor State: Stopped
  setMotorSpeeds(0, 0);

  // Short delay before startup run
  delay(1000);
}

// ==========================================
// 5. MAIN CONTROL LOOP
// ==========================================
void loop() {
  readAllSensors();

  // -------------------------------------------------------------
  // CONDITION 1: OBSTACLE AHEAD -> HARD CORNERING / PIVOT
  // -------------------------------------------------------------
  if (distFront < FRONT_THRESHOLD && distFront > 0) {
    executePivotTurn();
  } 
  // -------------------------------------------------------------
  // CONDITION 2: CLEAR AHEAD -> HIGH-SPEED PD WALL-CENTERING
  // -------------------------------------------------------------
  else {
    // Determine wall centering strategy based on available side walls
    if (distLeft > 0 && distRight > 0 && distLeft < 60 && distRight < 60) {
      // Both walls detected: Center in middle of corridor
      currentError = distLeft - distRight;
    } 
    else if (distLeft > 0 && distLeft < 60) {
      // Only Left wall detected: Maintain 20 cm distance from Left wall
      currentError = (distLeft - 20.0) * 1.5;
    } 
    else if (distRight > 0 && distRight < 60) {
      // Only Right wall detected: Maintain 20 cm distance from Right wall
      currentError = (20.0 - distRight) * 1.5;
    } 
    else {
      // Open space / No close side walls: Drive straight forward
      currentError = 0.0;
    }

    // Calculate PD Steering Correction
    float derivative = currentError - lastError;
    float steeringAdjustment = (Kp * currentError) + (Kd * derivative);
    lastError = currentError;

    // Apply differential PWM speed control
    int leftMotorPWM  = BASE_SPEED - steeringAdjustment;
    int rightMotorPWM = BASE_SPEED + steeringAdjustment;

    // Constrain PWM values to safe hardware limits
    leftMotorPWM  = constrain(leftMotorPWM, MIN_SPEED, MAX_SPEED);
    rightMotorPWM = constrain(rightMotorPWM, MIN_SPEED, MAX_SPEED);

    // Drive forward with differential steering
    digitalWrite(IN1, HIGH);
    digitalWrite(IN2, LOW);
    digitalWrite(IN3, HIGH);
    digitalWrite(IN4, LOW);

    setMotorSpeeds(leftMotorPWM, rightMotorPWM);
  }
}

// ==========================================
// 6. HARDWARE & SENSOR HELPER FUNCTIONS
// ==========================================

/**
 * Fast ultrasonic distance reading routine with tight pulse timeout.
 */
float getDistance(int trigPin, int echoPin) {
  digitalWrite(trigPin, LOW);
  delayMicroseconds(2);
  digitalWrite(trigPin, HIGH);
  delayMicroseconds(10);
  digitalWrite(trigPin, LOW);

  // Read pulse width with microsecond timeout (prevents code stall)
  long duration = pulseIn(echoPin, HIGH, SENSOR_TIMEOUT);

  if (duration == 0) {
    return 150.0; // Return max distance out of range
  }
  
  return (duration * 0.0343) / 2.0; // Convert microseconds to cm
}

/**
 * Batch read all three range sensors
 */
void readAllSensors() {
  distFront = getDistance(TRIG_FRONT, ECHO_FRONT);
  distLeft  = getDistance(TRIG_LEFT, ECHO_LEFT);
  distRight = getDistance(TRIG_RIGHT, ECHO_RIGHT);
}

/**
 * Direct PWM Output Helper
 */
void setMotorSpeeds(int leftSpeed, int rightSpeed) {
  analogWrite(ENA, leftSpeed);
  analogWrite(ENB, rightSpeed);
}

/**
 * High-speed wall escape / cornering decision execution
 */
void executePivotTurn() {
  // Determine open side (Turn toward the side with more space)
  if (distLeft > distRight) {
    // Spin Left in place
    digitalWrite(IN1, LOW);
    digitalWrite(IN2, HIGH);
    digitalWrite(IN3, HIGH);
    digitalWrite(IN4, LOW);
    setMotorSpeeds(MAX_SPEED, MAX_SPEED);
  } else {
    // Spin Right in place
    digitalWrite(IN1, HIGH);
    digitalWrite(IN2, LOW);
    digitalWrite(IN3, LOW);
    digitalWrite(IN4, HIGH);
    setMotorSpeeds(MAX_SPEED, MAX_SPEED);
  }

  // Pivot until front path is cleared
  while (getDistance(TRIG_FRONT, ECHO_FRONT) < FRONT_THRESHOLD + 10) {
    delay(10);
  }
}
